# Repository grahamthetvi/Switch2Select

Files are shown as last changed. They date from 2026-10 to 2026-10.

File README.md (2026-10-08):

# Switch2Select

Switch2Select is a four-option switch device for students with cortical visual impairment. A student has four direct switches and one scan switch. A partner sees four toy outputs, volume buttons, a device button, and the power switch. One large target is on screen at a time. Choosing an option can light the ring behind that card, speak the port, show a picture, video, or simple game, and briefly close a contact for a battery toy.

An ESP32 DevKit runs an open Wi-Fi access point named Switch2Select and serves the page from a microSD card. A DFRobot Gravity Speech Synthesis Module V2.0 (DFR0760) speaks when no browser page is connected to the device. Two buttons change the volume. A third button, the same size, talks to the screen and repeats which port is in use. A DaierTek 20 mm round SPST rocker switches the USB +5 V lead from a power bank or a 5 V adapter. There is no custom circuit board. Connections are soldered or joined with WAGO 221 connectors.

A stand on the lid holds an iPad in landscape. The full stand leans 18 degrees back from vertical, and it can hold four 3 by 5 inch cards stood up in place of the iPad. The simple stand leans 8 degrees and holds the iPad. There is no lamp above the input jacks. Those lamps would point at the student. The active port is spoken, and the light sits behind the card.

Build in the order below. Flash the board before you close the box. Keep the power source unplugged until the wiring section is finished.

## Tools

- Soldering iron, or WAGO 221 lever connectors if you are not soldering
- Wire strippers
- Flush cutters
- Screwdriver for the lid screws and panel hardware
- 3D printer
- Computer with the Arduino IDE, a USB cable to the ESP32 for programming, and a way to copy files to a microSD card

## Parts

- ESP32 DevKit with USB, 30-pin style
- SPI microSD module
- microSD card you can format as FAT32
- Five panel-mount 3.5 mm mono jacks for the inputs. Each one pushes into a 9.1 mm hole
- Four panel-mount 3.5 mm mono jacks for the toy outputs, in the same 9.1 mm holes
- 4-channel 5 V relay module whose coils are off when the input pin is HIGH
- Four WS2812B rings, 7 LEDs each, 23 mm outside diameter, 5 V, with DIN and DOUT
- One 330 ohm resistor, in series with the ring data line
- One 1000 µF capacitor, 6.3 V or higher, across the ring 5 V and ground at the first ring
- Four 10k resistors for pull-ups
- Three momentary push buttons, 11.8 mm wide. The panel hole is 12.0 mm (11.8 mm plus 0.2 mm clearance) so the button can be pushed in
- DaierTek 20 mm 2-pin SPST round rocker
- DFR0760 speech module with the speaker it ships with
- USB cable for power
- USB power bank or 5 V USB adapter
- Insulated hookup wire
- Four small zip ties, or a dot of hot glue, to keep the rings in their pockets
- PLA or PETG
- Four M3 screws, about 8 mm to 12 mm long, for the lid
- For the full stand: four M3×20 mm screws and four M3 nuts, to bolt the cap and the plate through the lid; four M3×6 mm screws, for the two rail extensions; two M3×10 mm screws, for the sliding side rails; two M3×12 mm screws and two M3 nuts, to join the card halves; two M3×12 mm screws and two M3 nuts, for the rear feet
- For the simple stand: four M3×10 mm screws and four M3 nuts, to bolt the cradle through the lid; two M3×6 mm screws, for the side stops

The enclosure corners are drilled for the lid screws. The lid holes are 3.4 mm clearance. Each bottom boss has a 2.8 mm pilot, 10 mm deep. On the full stand, the extension screws and the rail screws form their own threads in 2.8 mm pilots. On the simple stand, each side-stop screw forms its own thread in the stop and presses on the lip. The screws that bolt a stand through the lid use nuts on the underside of the lid.

## Print the enclosure

The assembled box is 200 mm by 140 mm by 55 mm, with 2.4 mm walls. The outside vertical corners have a 6 mm radius. On the flat faces the wall is still 2.4 mm. Raised numerals and marks stand 0.8 mm off the walls. Braille dots stand 0.9 mm off the walls, so a finished bottom measures about 141.8 mm front to back. Print two parts:

- `enclosure/switch2select-bottom.stl`
- `enclosure/switch2select-lid.stl`

Those files were exported from `enclosure/switch2select.scad`. To export them yourself, open that file in OpenSCAD and set `part` to `"bottom"` or `"lid"`. The value `"both"` draws the bottom and the lid side by side. The customizer accepts `bottom`, `lid`, or `both`.

The two long walls are different. Look at the holes before you wire anything.

The student wall has four 9.1 mm jack holes in a row and one more 9.1 mm jack centered on the lower row. There is no lamp above those jacks. Input holes and output holes are the same size, so the female jack can be pushed in. On the inside of the wall, a cradle 27.3 mm deep holds the whole jack cylinder. A shoulder at the back of the cradle stops that cylinder, and a 7.0 mm hole through the shoulder (a 6.6 mm cord plus 0.4 mm clearance) lets the lead leave the back of the jack. A stem stands just past that hole, beside the cord path, so the lead can be wrapped after it leaves the cylinder and a pull does not yank the jack out. Raised numerals 1, 2, 3, and 4 sit beside the upper jacks. Grade 1 braille for 1, 2, 3, and 4 sits on the other side of those jacks. The center jack is the scan input. The braille word scan sits under it. Braille dots are 0.9 mm high and 1.6 mm across, with 2.5 mm between dot centers in a cell and 6.5 mm between cells. Facing this wall, the four option jacks run left to right as 1, 2, 3, 4. Their centers are 40 mm, 80 mm, 120 mm, and 160 mm from the left end. Input jacks are 28 mm up from the outside bottom. The scan jack is 16 mm up, at the middle of the wall (100 mm from either end).

The partner wall has four 9.1 mm toy-jack holes with the same 27.3 mm cradle, cord hole, and cord stem, and raised numerals 1, 2, 3, and 4. Grade 1 braille for 1, 2, 3, and 4 sits beside those jacks, on the side opposite the numeral. Numeral 1 is at the same end of the box as numeral 1 on the student wall. Toy jacks are 40 mm up from the outside bottom. The lower row, left to right when you face this wall, is:

- Volume down, a 12.0 mm hole (an 11.8 mm button plus 0.2 mm clearance) with a minus mark, 16 mm up. A 9 mm square backing sits 7.55 mm behind the inner face of the wall. Braille for the word minus is under the hole.
- Volume up, the same 12.0 mm hole, 9 mm square backing, and plus mark, 16 mm up. Braille for the word plus is under the hole.
- Device, the same 12.0 mm hole and 9 mm square backing, with a square mark, 16 mm up. Braille for the word use is under the hole. This button does not change the volume and it does not pulse a toy.
- Power rocker, a 20 mm hole, 16 mm up. The body behind the panel is about 25.4 mm deep, with snap wings and two terminals, and the inside stays clear so that body can sit in the box. Braille for the word power sits between this hole and the toy jacks.
- USB cable slot, 12 mm wide by 8 mm tall, centered 16 mm up
- microSD slot, 16 mm wide by 3 mm tall, centered 16 mm up

The lid has a speaker grill in the center. The grilled area is 42 mm by 32 mm, with seven slots, each 3 mm wide. Behind the grill, toward the partner edge, a 12 mm by 10 mm port lets the ring cable into the box. Four 3.4 mm holes in a row take the stand bolts. The lid lip is sized with a 0.4 mm gap inside the bottom rim. If a lid will not seat, sand the lip lightly until it drops in.

Inside, on the floor under that port, two posts and a bar are a tie point for the ring cable.

The enclosure, the stand, and the wiring are CERN-OHL-W v2. If you share a modified enclosure, stand, or wiring layout, release those hardware changes under the same license. The full terms are in the License section.

## Print the stand

The lid has four 3.4 mm holes in a row behind the speaker grill. The full stand and the simple stand both bolt through those holes. Print one stand. The student looks at the screen, or at the cards on the full stand. The partner wall stays open, so the toy plugs, the buttons, the rocker, the USB lead, and the microSD card are still reachable.

### Full stand

The full stand leans 18 degrees back from vertical. It holds an iPad or four cards. Two feet drop to the table at the rear corners, clear of the partner-wall plugs.

Print:

- `enclosure/stand-cap.stl`, one. The word FRONT is the student edge. The ring pockets are not on this part. Lay it flat, text up.
- `enclosure/stand-plate.stl`, one. Lay the flat foot on the bed. The back rises from it. The part is about 175 mm tall, so the printer needs that much vertical room. The ledge sticks out at about 18 degrees above the bed. Turn supports on under the ledge.
- `enclosure/stand-extension-left.stl` and `enclosure/stand-extension-right.stl`, one each. Same orientation as the plate, with supports under the ledge. Each is about 138 mm wide and 175 mm tall.
- `enclosure/stand-rail.stl`, two. Print one as exported and mirror the other in the slicer. The slot faces up. The small fin is the side that meets the iPad or the card panel. After mirroring, the two fins face each other.
- `enclosure/stand-cards-left.stl` and `enclosure/stand-cards-right.stl`, one each, only if you want the cards. Lay them with the round pockets up. Numerals 1 and 2 are on the left half. Numerals 3 and 4 are on the right half. Each half is about 183 mm by 151 mm.
- `enclosure/stand-foot.stl`, two. Lay it on the broad face. The screw hole is the short tunnel through the tab.

The cap, the rails, the card halves, and the feet print without supports.

Those files were exported from `enclosure/stand.scad`. Set `part` to `cap`, `plate`, `extension-left`, `extension-right`, `rail`, `cards-left`, `cards-right`, or `foot`. The value `assembly` draws the stand on the box, with a sample iPad and the card panel in the same ledge so you can see that both fit. You use one or the other, not both at once.

The ledge is 12 mm deep, so a bare iPad from 5.1 mm to 7.5 mm thick sits in it, and so does the card panel. A case has to be thinner than 11 mm. The iPad leans on the back. The shelf at the bottom of the slope keeps it from sliding toward the student. A low wall stands at the front of that 12 mm channel. The side rails set the width. Ticks on the ledge read `mini`, `10`, `13`, and `card`. Snug the rails to the real device. The `10` tick is the 10.2 inch iPad (7th, 8th, and 9th generation). The 10.9 inch and 11 inch Air and Pro models are within 3 mm of that tick.

Landscape widths, long edge on the ledge:

| Model | Width | Height | Thickness |
| --- | --- | --- | --- |
| iPad mini 6 and 7 | 195.4 mm | 134.8 mm | 6.3 mm |
| iPad 9.7 inch | 240 mm | 169.5 mm | 6.1 mm to 7.5 mm |
| iPad 7th, 8th, and 9th generation (10.2 inch) | 250.6 mm | 174.1 mm | 7.5 mm |
| iPad 10th generation and iPad A16 (10.9 inch) | 248.6 mm | 179.5 mm | 7.0 mm |
| iPad Air 11 inch and iPad Pro 11 inch (2018–2022) | 247.6 mm | 178.5 mm | 5.9 mm to 6.1 mm |
| iPad Pro 11 inch M4 | 249.7 mm | 177.5 mm | 5.3 mm |
| iPad Air 13 inch and iPad Pro 12.9 inch | 280.6 mm | 214.9 mm | 5.9 mm to 6.4 mm |
| iPad Pro 13 inch M4 | 281.6 mm | 215.5 mm | 5.1 mm |

Portrait works too. Slide the rails in until they touch the sides. The center plate alone is 200 mm wide, which covers an iPad mini in landscape. The side rails still need the two extensions under them, because the rail is wider than the spare ledge at the end of the center plate. Every larger iPad needs the extensions for the ledge as well. The card panel is 349 mm wide, so it needs the extensions too.

The cards are 3 inch by 5 inch (76.2 mm by 127 mm), stood up, four across. The slot is 1.6 mm wider and 1.8 mm deep, so a laminated card slides in from the top. To use a different card, change `card_w` and `card_h` at the top of `enclosure/stand.scad` and export the two card halves again.

Behind each card is a round seat 23.8 mm across and 2.4 mm deep, open on the back, with a 10 mm hole through to the card. That is the pocket for a 23 mm WS2812B ring. The 10 mm hole is smaller than the ring, so the ring cannot fall toward the student. Two 2.6 mm holes beside the seat take a zip tie across the back of the ring. A trench on the back carries the wires to the notch in the plate, then through the port in the cap and the lid.

Bolt the extensions to the plate with the four M3×6 screws. The thin lap on each extension sits in the recess at the end of the plate foot. The hole under the lap is about 7 mm deep and ends inside the foot, and an M3×6 screw draws the lap down. Bolt the cap and the plate foot to the lid with the four M3×20 screws and nuts. The nuts are on the underside of the lid, so do this before you screw the lid onto the box, or take the lid off to reach them. The four holes are in a row behind the speaker grill. The word FRONT on the cap points at the student. Bolt a foot to each rear tab of the cap. The leg reaches the table, 176 mm from the student edge. Fit both feet. The center of a 10.2 inch iPad sits about 5 mm behind the box, and the center of a 13 inch iPad sits about 13 mm behind the box. The feet carry that weight.

Slide a side rail onto each end of the ledge, with the extensions already bolted on, and tighten its screw until the rail stays put. For an iPad, set the rails to the width and sit the iPad on the ledge, long edge down, screen toward the student. For cards, screw the two halves together with the two M3×12 screws and nuts. The nuts sit in the hex pockets on the back of the half marked 1 and 2. Press each ring into a pocket from the back, LEDs toward the card, and tie or glue it. Seat the panel in the ledge and bring the rails in against its sides. The cable drops through the port. Tie it to the bar on the floor of the box.

### Simple stand

The simple stand is one cradle and two side stops. The back leans 8 degrees from vertical and is 6 mm thick. The cradle's outside corners have a 6 mm radius, and the edges of the back have a 2 mm radius. Each side stop's outside corners have a 1 mm radius. The lip the stops grip stays straight. Behind that plate, the cradle fills in to the rear edge of the shelf, so the back is solid where it joins the base. A bare iPad sits on the shelf and rests against that back. The lip on the student side of the shelf is 8 mm tall and 2.4 mm thick. The open gap from the lip to the back is 13.5 mm, so an iPad from 5.1 mm to 7.5 mm thick can lean fully back. The lip stops the bottom edge if the iPad slides toward the student. The lip starts about 1 mm behind the speaker grill, so the grill stays clear.

Eight degrees is a small lean, and it holds the iPad against the back. The center of a 13 inch iPad (215.5 mm tall and 5.1 mm thick) lands about 24 mm in front of the rear edge of the box. The cradle carries that iPad on the lid. The back is 160 mm along the slope, which covers an iPad mini. The top of a 10 inch or 13 inch iPad stands above the back and still leans on it.

Print:

- `enclosure/stand-simple.stl`, one. Lay the flat base on the bed. The lip and the back rise from it. The part is about 165 mm tall. It prints in PLA or PETG without supports.
- `enclosure/stand-simple-stop.stl`, two. Lay each one as exported. The slot faces up and the flat cap is on the bed. The fin is the short upright at one end. The part is about 74 mm long and 12 mm tall. Mirror the second stop left to right in the slicer, so the fins face each other and both screw bosses stay on the student side of the lip.

Those files were exported from `enclosure/stand-simple.scad`. Set `part` to `cradle` or `stop`. The value `assembly` draws the cradle and the stops on the box with a 13 inch iPad.

The cradle is 200 mm wide. An iPad mini in landscape (195.4 mm) sits on it with the stops near the ends. Each stop reaches about 45 mm past the box, which covers the wider models through a 13 inch iPad (281.6 mm). The widths are in the table above. Slide each stop on from the end of the lip until the fin meets the iPad.

Bolt the cradle to the lid with four M3×10 screws and nuts. Use a socket head or a pan head, about 5.5 mm to 5.6 mm across, so the head sits in the counterbore. Each counterbore is 6.2 mm across and 3.2 mm deep. The nuts are on the underside of the lid, so do this before you screw the lid onto the box, or take the lid off to reach them. The lip faces the student. The cable port stays open through the shelf.

Set the iPad on the shelf, long edge down, screen toward the student. It leans on the back. Bring each stop in until the fin touches the side. The M3×6 screw goes through the boss on the student side of the stop and presses the face of the lip. Tighten it until the stop stays put.

The card panel, the ring pockets, and the rear feet belong to the full stand.

## Flash the firmware

Flash the ESP32 before you mount it and before you depend on the relay pins. The sketch drives the relay outputs HIGH, which holds the coils off.

1. Install the Arduino IDE.
2. In Boards Manager, install the **esp32** package by Espressif Systems.
3. Under Tools, Board, choose **ESP32 Dev Module** (the `esp32dev` board). Leave the other board options at the package defaults unless your DevKit needs a different flash size.
4. In Library Manager, install these libraries:
   - **ArduinoJson** by Benoit Blanchon, version 6. This sketch uses `DynamicJsonDocument`. ArduinoJson 7 does not provide that type.
   - **WebSockets** by Markus Sattler (Links2004). The sketch includes `WebSocketsServer.h` from that library.
   - **DFRobot_SpeechSynthesis_V2**. This library is MIT, copyright DFRobot Co.Ltd. Keep their copyright notice with the library.
   - **Adafruit NeoPixel** by Adafruit. The sketch includes `Adafruit_NeoPixel.h`. On the ESP32 this library drives the rings with the RMT peripheral, so the Wi-Fi radio can stay up.
5. Open `firmware/Switch2Select/Switch2Select.ino`. Leave `pins.h`, `device.h`, `device.cpp`, `web.h`, and `web.cpp` in that same folder. The folder name stays `Switch2Select`.
6. Plug the DevKit into the computer with its own USB cable. The power-bank cable stays unplugged. Select the serial port that appears. If no port appears, install the USB serial driver for the chip on your board.
7. Upload the sketch.
8. Open the Serial Monitor at **115200** baud. After reset, the monitor prints the access-point address. With the ESP32 Arduino core defaults, that address is `192.168.4.1`.

The USB serial port and the speech module both use 115200. They are separate UARTs. Speech is on Serial2, pins 16 and 17, described below.

### Pins

GPIO 0, 2, and 12 are strapping pins. Leave them unconnected.

| Option | Numeral | Input GPIO | Input pull-up | Relay GPIO |
| --- | --- | --- | --- | --- |
| 0 | 1 | 34 | External 10k to 3.3 V | 4 |
| 1 | 2 | 35 | External 10k to 3.3 V | 15 |
| 2 | 3 | 36 | External 10k to 3.3 V | 21 |
| 3 | 4 | 39 | External 10k to 3.3 V | 22 |

Other connections:

- Scan jack: GPIO 32. Internal pull-up. The sketch enables it.
- Volume up (plus button): GPIO 27. Internal pull-up.
- Volume down (minus button): GPIO 33. Internal pull-up.
- Device button (square mark): GPIO 14. Internal pull-up.
- Card rings: GPIO 13 is the data pin. One chain of four 7-LED rings. GPIO 25 and GPIO 26 are unused.
- Speech, Serial2: GPIO 16 is the ESP32 receive pin and goes to the module D/T pin. GPIO 17 is the ESP32 transmit pin and goes to the module C/T pin. 115200 baud, 8 data bits, no parity, 1 stop bit.
- microSD SPI: CS GPIO 5, MOSI GPIO 23, MISO GPIO 19, SCK GPIO 18.

GPIO 34, 35, 36, and 39 are input-only. They have no internal pull-up. Each one needs the external 10k to 3.3 V. The scan, volume, and device pins use the ESP32 internal pull-ups, so they do not get a 10k resistor.

A press is active-low. The firmware accepts it after the pin has been low and stable for 40 ms. Holding a switch does not repeat the action.

## Prepare the microSD card

Format the card FAT32. Copy the files and folders that are inside `sd-card` so that `config.json` sits at the root of the card, next to `www`, `media`, and `games`.

These paths are part of the project:

- `/config.json`
- `/www/index.html`
- `/www/style.css`
- `/www/app.js`
- `/www/switch2select.js`
- `/www/edit.html`
- `/www/edit.css`
- `/www/edit.js`
- `/www/isolate.js`
- `/media/yes.svg`
- `/games/common.css`
- `/games/look/index.html`
- `/games/chase/index.html`
- `/games/pop/index.html`
- `/games/drum/index.html`

`yes.svg` is a yellow circle on a black square. The sample Play choice opens `/games/look/index.html`. Look keeps one yellow shape moving on black. Chase sends a ball between four places. Pop raises bubbles in four columns. Drum is four drums. In each game the four switches play the four places, left to right, and the scan switch plays too. A game keeps those switches while it is open. The choices return after the switches have been quiet for about a minute. The device button leaves sooner.

The sample `config.json` points the Look option at `/media/pulse.mp4`, which is included. The firmware serves `.html`, `.css`, `.js`, `.json`, `.svg`, `.mp4`, `.wav`, `.png`, `.jpg`, and `.jpeg`.

The device reads `/config.json` at startup. The setup page can write that file and apply it while the device stays on. After you edit the file on a computer, turn the rocker off and on. Use a plain text editor and keep the JSON valid, with exactly four objects in `options`. A file the firmware cannot parse is ignored in memory. The card copy is left as written. The in-memory fallback is auto scan, a 3 second step, a 1 second pulse length, volume 5, and the labels One, Two, Three, and Four, with toy pulses off.

Fields:

- `scanMode` is `"auto"` or `"step"`. Any value other than `"step"` is treated as auto. Auto is the sample and the fallback.
- `scanDelayMs` is how long, in milliseconds, the highlight stays on one option during auto scan. A missing or zero value becomes 3000.
- `outputPulseMs` is how long, in milliseconds, a toy contact stays closed. A missing value becomes 1000. The sample uses 1000, about one second.
- `volume` is an integer from 0 to 9. The sample uses 5. The volume buttons and the setup page update this field on the card when the card is mounted. Values below 0 or above 9 are clamped.
- `ringLevel` is an integer from 0 to 9. The sample uses 4. It sets how bright the card ring is. 0 leaves the rings off. The device button does not change it. The setup page changes it. A file edit is used after the rocker is turned off and on. A missing value becomes 4.
- `options` is four entries. Index 0 is numeral 1.

Each option:

- `label` is the short word shown while scanning, and the word spoken when the highlight moves. The firmware keeps 47 characters.
- `phrase` is spoken when that option is selected and the speech module is the one talking. If `phrase` is empty, the module speaks `label`. The firmware keeps 95 characters.
- `type` is `image`, `video`, `game`, or `tts`. An empty or unknown type is treated as `tts`.
- `src` is a path on the card, such as `/media/yes.svg`. Leave it empty for a `tts` option. The firmware keeps 63 characters.
- `background` is the screen color behind the target, as `#RRGGBB`. Empty becomes `#000000`.
- `color` is the word color, as `#RRGGBB`. Empty becomes `#ffff00`.
- `pulseOutput` is `true` or `false`. `true` closes that option's relay for `outputPulseMs` when the option is selected. `false` leaves the toy contact open. A missing flag is false.

The sample card is:

| Numeral | Label | Type | On select | Toy pulse |
| --- | --- | --- | --- | --- |
| 1 | Yes | image | Yellow circle, speaks "Yes" | Yes |
| 2 | Look | video | Plays `/media/pulse.mp4`, speaks "Look" | No |
| 3 | Play | game | Look game, speaks "Play" | No |
| 4 | Help | tts | Shows and speaks "I need help" | Yes |

Backgrounds in the sample are black. Word colors are yellow, except Look, which is red.

## Wiring

Unplug the power bank or adapter. Leave the rocker off. The DevKit may stay on the bench until the joints are done.

The DaierTek rocker switches the USB +5 V lead only. It must not be wired to household mains. Toy jacks are dry contacts on the relay normally-open pair, for a battery toy's own switch circuit. They are not a motor supply and they are not mains.

Use the tip and sleeve lugs on each mono jack. If a jack has an extra lug that switches when a plug is inserted, leave that lug unused.

### Power and ground

Cut the red conductor of the USB power cable and put the rocker in series with it. The rocker has two pins. One pin is the red wire from the power bank or 5 V adapter. The other pin is the switched +5 V that feeds the electronics. Black ground does not go through the rocker. Run ground straight through to:

- ESP32 GND
- Relay module GND
- DFR0760 GND
- SPI microSD module GND

Switched +5 V goes to:

- The ESP32 pin labeled 5V or VIN
- Relay module VCC
- DFR0760 5 V
- The card rings' 5 V pads, with the 1000 µF capacitor across that pair at the first ring

Program the board from the DevKit USB socket with this power cable unplugged, so the computer and the power bank are not both feeding 5 V. The enclosure slot is the exit for the power cable. It is 12 mm by 8 mm.

The 10k pull-ups use the ESP32 pin labeled 3.3V. They do not use 5 V.

### Relays and toy jacks

HIGH on a relay GPIO means the coil is off. The firmware writes HIGH on GPIO 4, 15, 21, and 22 before it sets those pins as outputs, so a reset does not pulse a toy. Use a 4-channel 5 V module that works this way: a HIGH input leaves the coil off, and a LOW input turns that coil on.

If the board has a jumper between JD-VCC and VCC, leave the jumper fitted. The coils then use the same switched 5 V as the rest of the module. This build has no separate coil supply.

One relay channel serves one option:

- Numeral 1, relay input GPIO 4
- Numeral 2, relay input GPIO 15
- Numeral 3, relay input GPIO 21
- Numeral 4, relay input GPIO 22

For each channel, connect the normally-open terminal (NO) and the common terminal (COM) to the tip and sleeve of that option's toy jack. Either lug may take either relay terminal. A dry contact has no polarity from this device. Leave the normally-closed terminal (NC) unconnected. No ESP32 pin connects to a toy jack. The toy plug replaces the toy's own switch: the two conductors that the toy's button used to join. When the firmware selects an option with `pulseOutput` true, it drives that GPIO LOW for `outputPulseMs`, then returns it HIGH.

### Input jacks and volume buttons

Each input jack: sleeve to GND, tip to its GPIO.

- Numeral 1 tip: GPIO 34, and a 10k resistor from that GPIO to 3.3 V
- Numeral 2 tip: GPIO 35, and a 10k resistor from that GPIO to 3.3 V
- Numeral 3 tip: GPIO 36, and a 10k resistor from that GPIO to 3.3 V
- Numeral 4 tip: GPIO 39, and a 10k resistor from that GPIO to 3.3 V
- Scan tip: GPIO 32. Sleeve to GND. No external resistor.

Volume buttons and the device button are momentary switches, not jacks. One side of each button goes to GND.

- Plus button, the volume-up mark: GPIO 27
- Minus button, the volume-down mark: GPIO 33
- Device button, the square mark: GPIO 14

Match numeral 1 on the student wall to numeral 1 on the partner wall. The walls face opposite directions, so the left-hand jack on one wall is not numeral 1 on the other wall.

### Card rings

The rings replace lamps on the student wall. Only the ring behind the highlighted card is on. Its color is that option's `color`. `ringLevel` in `config.json` is 0 through 9. The sample uses 4. Level 0 leaves every ring dark. The firmware never turns all four rings on at once.

Power the rings from the switched 5 V rail, the same rail as the ESP32 VIN pin. Do not power them from the 3.3 V pin. Ground is the common ground. Put the 1000 µF capacitor across 5 V and ground at the first ring.

GPIO 13 goes to the 330 ohm resistor. The other side of the resistor goes to DIN on the port 1 ring. Port 1 is the student's left, the same end as numeral 1. Chain DOUT of each ring to DIN of the next, left to right, port 1 then 2 then 3 then 4. Share 5 V and ground with every ring. Keep the data lead short. These rings usually take the ESP32's 3.3 V data over that short lead. If the first ring never lights, the speech and the page still work.

At startup the firmware lights the port 1 ring and leaves the other three off. That ring follows the highlighted port afterward. The pocket is 23.8 mm across. Seat the ring from the back of the card panel, LEDs toward the card, and hold it with a zip tie through the two holes beside the pocket or with a dot of hot glue. The 10 mm hole in front of the ring lets the light reach the back of the card.

### Speech module

Set the switch on the DFR0760 to UART before you apply power. Connect module 5 V and GND as in the power step. The speaker stays on the module's speaker terminals.

- Module D/T to ESP32 GPIO 16
- Module C/T to ESP32 GPIO 17

D/T is the module's transmit pin. C/T is the module's receive pin. The firmware talks to it at 115200 baud and sends the stored volume after the module answers.

### microSD module

- CS to GPIO 5
- MOSI to GPIO 23
- MISO to GPIO 19
- SCK to GPIO 18
- GND to the common ground

Power the SPI module from the supply printed on that board. A module marked for 5 V, with its own regulator, uses the switched 5 V rail. A 3.3 V module uses the ESP32 3.3 V pin. Seat the module so a card pushed through the 16 mm by 3 mm slot enters the socket.

### Pins to leave alone

Do not use GPIO 0, 2, 12, 25, or 26. Do not land a toy jack, a relay contact, or the rocker on an ESP32 pin. Before you apply power, check that each toy jack's two lugs go only to one relay's NO and COM.

## Assembly

1. Confirm the student wall by the single lower jack with the braille word scan under it. There are no lamp holes on that wall. Confirm the partner wall by the 20 mm rocker hole, the three button holes (minus, plus, and the square mark), and the two slots.
2. Push the four input jacks and the scan jack into the 9.1 mm holes until each 27.3 mm cylinder sits in its cradle against the back shoulder. Feed each lead out through the cord hole and wrap it around the stem just beyond that hole.
3. Push the four toy jacks into the partner-wall holes the same way, each beside its matching numeral, and wrap those leads on the stems beyond the cord holes. Seat each of the three buttons in its hole so it meets the 9 mm square backing. Mount the 20 mm rocker in the lower row. Leave the space behind the rocker clear for the switch body and its two terminals.
4. Route the USB power cable out through the 12 mm by 8 mm slot.
5. Place the microSD socket behind the 16 mm by 3 mm slot.
6. Place the DFR0760 speaker on the inside of the lid, facing the grill. Bolt the stand to the lid before this lid goes back on the box, so you can reach the nuts. On the full stand, that is the cap and the plate with the four M3×20 screws. On the simple stand, that is the cradle with the four M3×10 screws, heads in the counterbores. The ring cable comes through the 12 mm by 10 mm port and ties to the bar on the floor. The simple cradle leaves that port open.
7. Label the outside of the student wall **Inputs** and the outside of the partner wall **Toys**. The raised numerals show which channel is which. The written labels are there so the two jack types are not swapped later.
8. Insert the FAT32 card.
9. Set the lid on the rim and fasten the four M3 screws through the lid into the corner bosses. The stand, if you bolted it to the lid, comes with the lid.

## Power-on test

This is the behavior the firmware and the sample card are written to produce. Work through it in order. Use the sample `config.json`, which is auto mode.

1. Toys unplugged or plugged into the partner-wall jacks only. Turn the rocker on. The relays stay silent and the toy contacts stay open. If the speech module is connected and no browser is open, it says "Port one, Yes". If the card rings are wired, the port 1 ring lights in that option's color and the other three stay off. Nothing on the student wall lights.
2. On a phone, iPad, or computer, join the Wi-Fi network **Switch2Select**. The sketch sets no password.
3. Open `http://192.168.4.1`. The device redirects to the page on the card. You should see a single target, the Yes image (a yellow circle) for the sample's first option. The page says "Port one, Yes".
4. Press the switch plugged into input 1. The page selects Yes. The picture pops and stays while the word is spoken. Auto scan waits during that. Press input 4. The page selects Help and shows the words for that option. The matching ring is the one that lights.
5. Wait until the words have finished. In the default auto mode the highlight then moves about every 3 seconds, the page follows it, and the spoken port changes with it. The ring follows the same port.
6. Press the scan jack while an option is highlighted. In auto mode that press selects the highlighted option. It does the same work as pressing that option's direct jack, including the toy pulse when `pulseOutput` is true.
7. Press the plus and minus buttons. Volume moves in steps from 0 through 9 and is written back to `config.json` on the card. With the page open, that level is the browser speech level. With the page closed, it is the DFR0760 level. Press the device button (the square mark). It does not move the highlight and it does not pulse a toy. It says the port that is in use, for example "Port one, Yes". With the page open, a video starts again from the beginning. While a game is open, this button leaves the game and says the port. The four switches and the scan switch play the game.
8. Plug a battery toy's switch lead into toy jack 1 or toy jack 4. Select Yes or Help. The contact closes for about one second (`outputPulseMs` is 1000) and then opens. Select Look or Play. Those sample options have `pulseOutput` false, so their toy jacks stay open.
9. Close the browser page so nothing is connected to the device. Select Help again. The DFR0760 speaks "Port four, I need help". The toy contact still opens when the one-second pulse ends, including while the module is still speaking.

If the page is open and the module still speaks, reload the page. Speech belongs to the browser while a page is connected, and to the DFR0760 when it is not. Joining the Wi-Fi network without opening the page leaves speech on the module.

If the module never speaks with the page closed, check that its switch is on UART, that D/T goes to GPIO 16, and that C/T goes to GPIO 17.

### If a check fails

**Input and toy jacks swapped.** A press on the student wall does nothing to the highlight, because that jack is only a relay contact. A toy plugged into an input jack is on a GPIO and ground, which does not give it a timed relay closure. Turn the rocker off, unplug every toy, and move the jacks: inputs on the wall with the scan jack, toy outputs on the wall with the rocker.

**A relay clicks at boot.** A coil turned on. This firmware holds GPIO 4, 15, 21, and 22 HIGH, and HIGH means the coil is off on the module this guide uses. A click means an IN wire is on the wrong pin, that pin is being held low, or the module turns its coil on when the input is HIGH. Recheck the four relay GPIOs. Leave GPIO 0, 2, and 12 unused.

**No microSD card, or a card the board cannot mount.** Switch2Select still appears, and the relay pins still idle HIGH. The browser reports that the page was not found, because the page files are on the card. Speech uses the fallback words One, Two, Three, and Four. Toy contacts stay open, because that fallback sets every `pulseOutput` flag false. Volume changes last only until power is removed.

## Using the device

A partner prepares the card and the toy leads. A student uses the five switches on the input wall.

The partner changes the four choices on the setup page. On the student screen, tap Setup in the top corner, or open `http://192.168.4.1/www/edit.html`. A phone that has joined Switch2Select can open that address and leave the student screen in place. Save writes the card, and the device uses the new settings while it stays on. The sketch has to be the one that accepts that save. Flash it, and copy the `www` files onto the card, before you rely on the page.

The page edits scan mode, the time on each choice, how long a toy stays on, volume, card-light brightness, and each choice. A picture can be taken or chosen on the iPad. Remove background lifts the subject off a plain background, such as paper or a table, and can draw an outline in a chosen color. That work runs in the browser. The device Wi-Fi does not reach the internet, so bring a photo with a plain background when you can. Videos need to be short MP4 files. Photos and videos from the page are stored as `/media/1.png` and `/media/1.mp4`, and the same pattern for choices 2, 3, and 4. A game stays a page already on the card. Look, Chase, Pop, and Drum are the ones on the card. The setup page has a button for each.

Editing `config.json` on a computer still works. Copy the card back, then turn the rocker off and on. Volume buttons still write the volume into the file while the device is on.

There are four options, numbered 1 to 4. Speech names the port that is highlighted, and the ring behind that card is the only one lit. One target fills the screen. Nothing on the input wall points a lamp at the student.

**Auto** is the default (`scanMode` set to `"auto"`). The highlight moves on its own every `scanDelayMs` (3 seconds on the sample card). The scan switch selects the option that is in use. A direct switch selects that option immediately, in auto mode and in step mode.

**Step** (`scanMode` set to `"step"`) does not move the highlight by itself. The scan switch only moves the highlight to the next option. It does not select and it does not pulse a toy. The four direct switches still select.

A selection always updates the ring and the page. It closes that option's toy contact only when `pulseOutput` is true, and only for `outputPulseMs`.

Choosing a picture, words, or a video pauses auto scan so the student can look. A picture or the words stay up long enough to be spoken, then the scan continues from that choice. A video stays until it ends, or for about a minute and a half if it does not end. Choosing the same picture, words, or video again plays it again.

Choosing a game pauses auto scan and lends the five student switches to that game. Later presses stay in the game: they do not move the four choices and they do not pulse a toy. The opening press still can. The four direct switches play four places, left to right, matching jacks 1 to 4. The scan switch plays the moving bright place, or the next place in Look and Chase. The game keeps moving while it waits, so there is something to look at between presses. Presses keep the game open. After the switches have been quiet for about a minute, the choices return and auto scan continues from that game. The device button leaves at once and says the port. It does not play the game.

Speech depends on the page:

- While a browser has the page open, the browser speaks and the DFR0760 stays quiet.
- While no page is connected, the DFR0760 speaks the same moments. Moving the highlight speaks "Port one, Yes" and so on: the port, then the option `label`. Selecting an option speaks the port and then `phrase`, or `label` when `phrase` is empty.
- While a browser has the page open, moving the highlight speaks that same port cue. Selecting speaks the phrase, or the label, without the port in front of it, so the screen says the message.

The device button is the square mark on the partner wall. It does not select an option, move the scan, or close a toy contact. It repeats the port that is in use. On the page it also acts on what is already showing. A video plays again from the start. A picture or words are spoken again. While a game is open, the button leaves the game instead. With the page closed, the speech module only repeats the port cue.

On the page, scanning an `image` option shows the picture. Scanning any other type shows the label as a word. The word or picture eases larger and smaller so the screen is not still. Selecting an `image` pops the picture, a `video` plays `src`, a `game` loads `src` and then stays there while the switches play it, and a `tts` option shows the phrase (or the label if the phrase is empty). For `tts`, the browser speaks that phrase. For the other types, the browser speaks the label. A game is not loaded again on every switch. Each later switch is sent into the game.

Words drawn by `style.css` are bold uppercase Arial, with Helvetica Neue and then a generic sans-serif as the font fallbacks. The page uppercases the letters on screen. Speech still says the phrase as it is written in `config.json`. The letter fill is the option `color`. A red outline surrounds each letter. The area behind the target is the option `background`. In the sample, that is yellow letters with a red outline on black, except Look, whose letters are red with the same red outline.

Volume is 0 through 9 on the two partner-wall buttons. The card stores the level.

## Attribution

The interaction pattern is inspired by Chatterbox, designed by Stephan Dobri for Neil Squire / Makers Making Change.

Copyright (c) 2025, Neil Squire. Chatterbox source: https://github.com/makersmakingchange/Chatterbox

Switch2Select firmware, enclosure, and this guide are original.

Copyright (C) 2026 Switch2Select contributors.

Chatterbox firmware and CAD were not copied into this project.

## License

- Firmware is GPL-3.0-or-later. The license text is in [LICENSES/gpl-3.0.txt](LICENSES/gpl-3.0.txt). Copyright (C) 2026 Switch2Select contributors.
- Enclosure and wiring (hardware) are CERN-OHL-W v2. The license text is in [LICENSES/cern_ohl_w_v2.txt](LICENSES/cern_ohl_w_v2.txt). If you share a modified enclosure or wiring, release those hardware changes under the same license.
- This guide is CC BY-SA 4.0. Credit Neil Squire / Makers Making Change for the Chatterbox interaction model this started from, and Switch2Select contributors for this device. The license text is in [LICENSES/cc-by-sa_4.0.txt](LICENSES/cc-by-sa_4.0.txt).
- The DFRobot_SpeechSynthesis_V2 library is MIT, copyright DFRobot Co.Ltd. Keep their notice with the library when you install it.

There is no warranty. Safety and quality of built units are on the maker. The power rocker switches 5 V USB only. It must not be wired to household mains. Toy jacks are dry contacts on the relay normally-open pair, for a battery toy's own switch circuit, not a motor supply or mains.

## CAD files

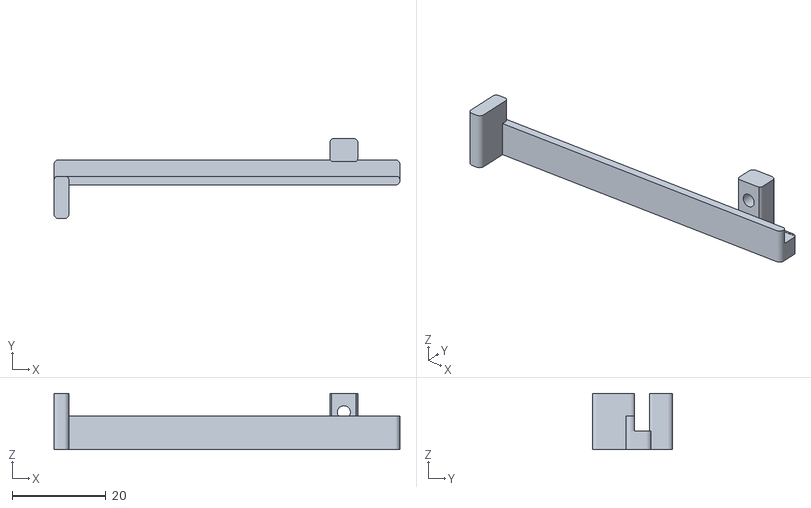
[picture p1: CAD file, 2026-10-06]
enclosure/stand-simple-stop.stl
74.0 x 17.2 x 12.1

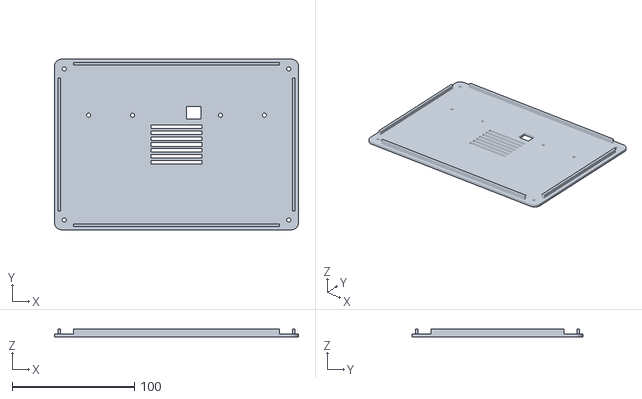
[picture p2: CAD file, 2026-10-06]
enclosure/switch2select-lid.stl
200.0 x 140.0 x 6.40

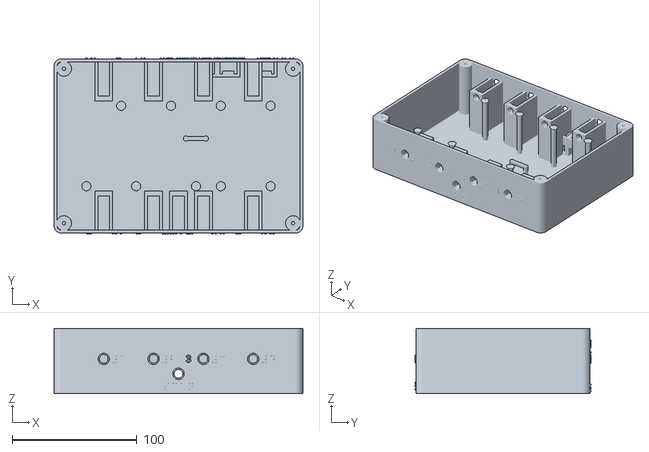
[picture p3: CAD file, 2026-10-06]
enclosure/switch2select-bottom.stl
200.0 x 141.8 x 52.6

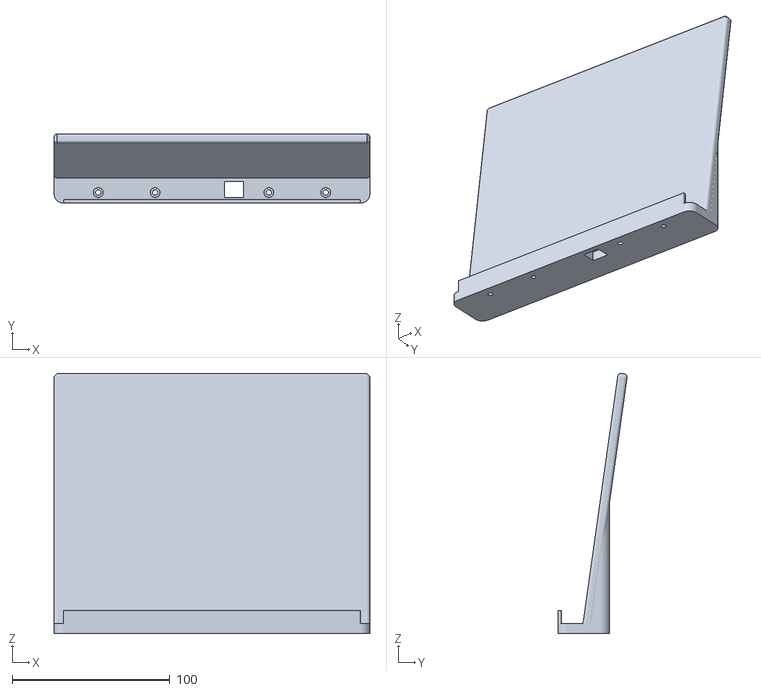
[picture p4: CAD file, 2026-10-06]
enclosure/stand-simple.stl
200.0 x 43.8 x 164.7

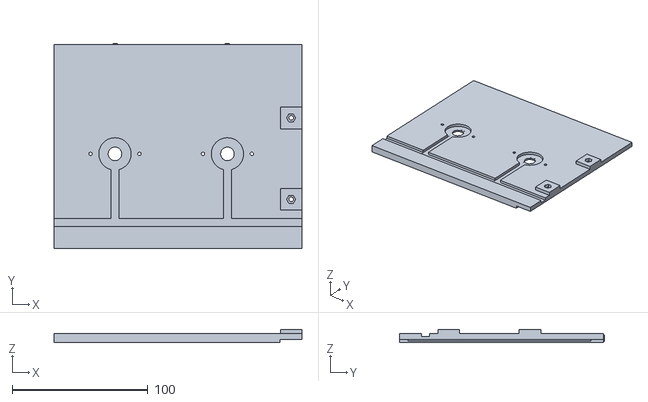
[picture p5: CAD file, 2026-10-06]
enclosure/stand-cards-left.stl
182.6 x 150.6 x 9.60

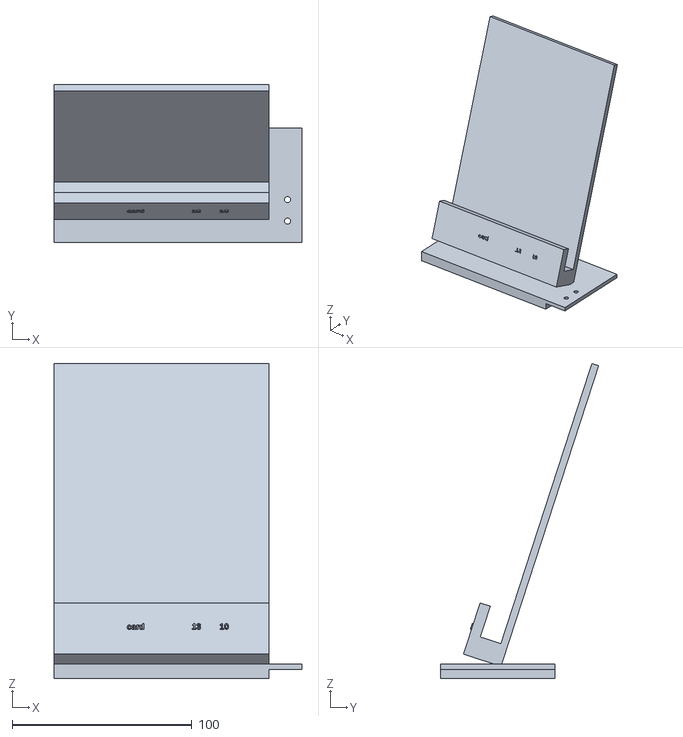
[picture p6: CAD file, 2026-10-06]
enclosure/stand-extension-left.stl
138.0 x 88.2 x 175.4

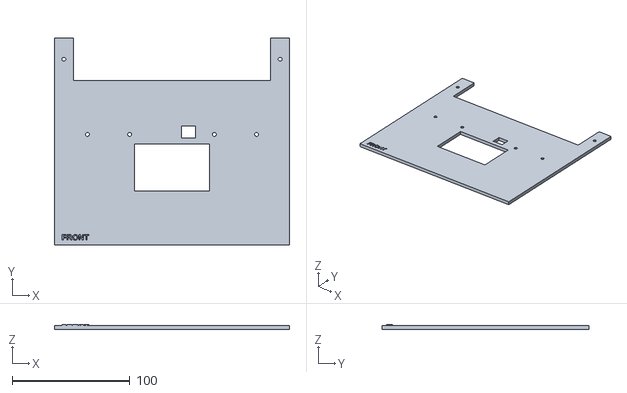
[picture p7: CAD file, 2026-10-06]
enclosure/stand-cap.stl
200.0 x 176.0 x 4.30

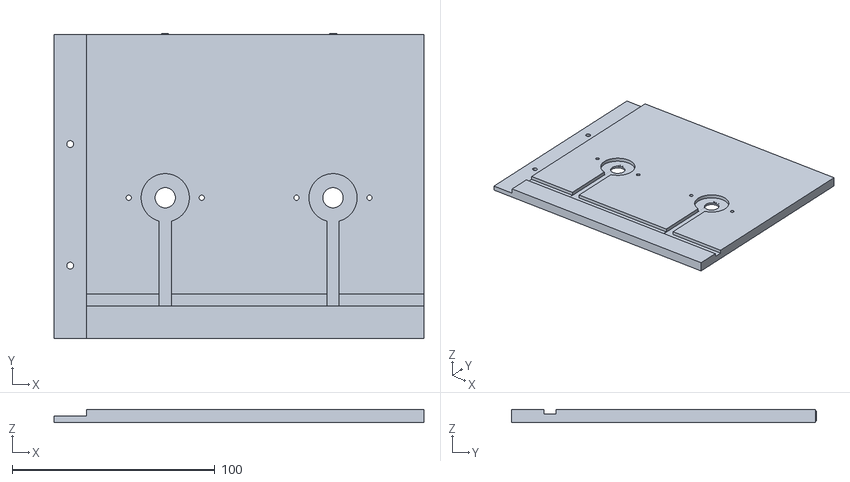
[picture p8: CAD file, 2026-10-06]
enclosure/stand-cards-right.stl
182.6 x 150.6 x 6.60

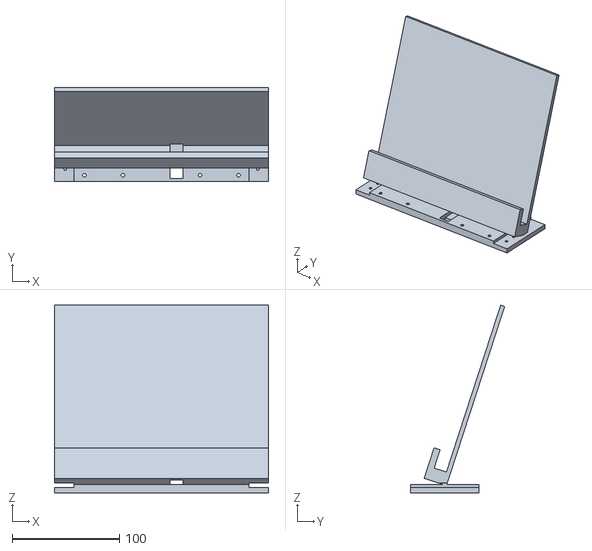
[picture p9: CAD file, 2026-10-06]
enclosure/stand-plate.stl
200.0 x 88.2 x 175.4

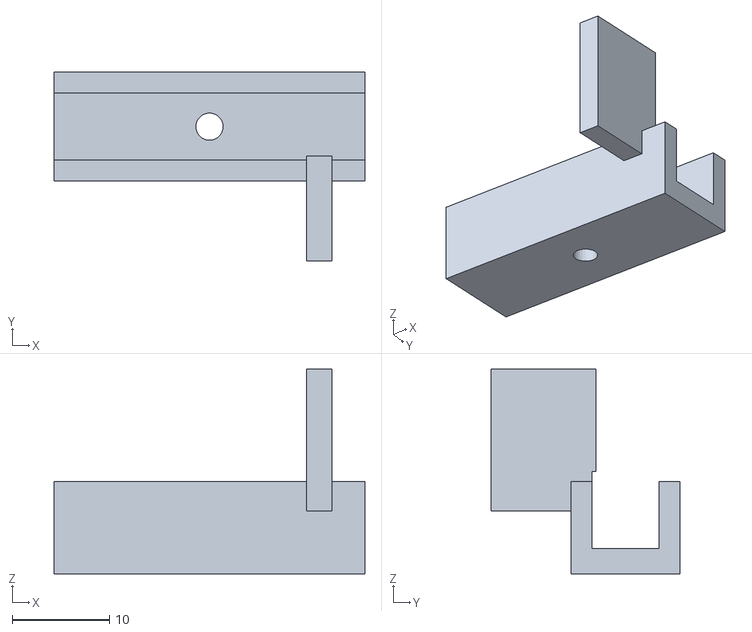
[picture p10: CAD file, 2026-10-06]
enclosure/stand-rail.stl
32.0 x 19.4 x 21.0

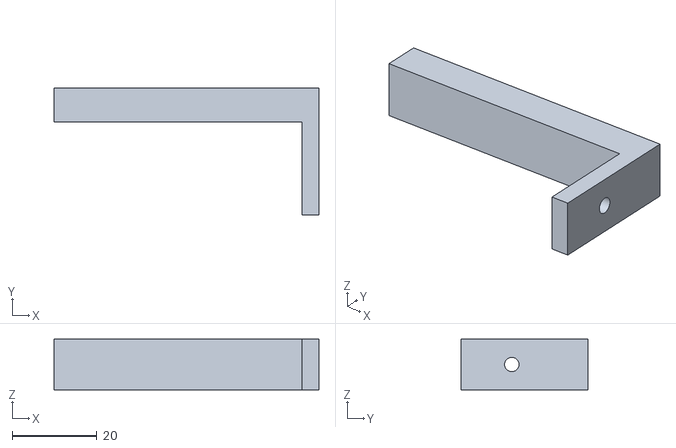
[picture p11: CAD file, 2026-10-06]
enclosure/stand-foot.stl
62.6 x 30.0 x 12.0

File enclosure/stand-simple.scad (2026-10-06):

// Switch2Select simple iPad stand
// Copyright (C) 2026 Switch2Select contributors
// SPDX-License-Identifier: CERN-OHL-W-2.0
//
// A second stand for the iPad. The full rail, card panel, and rear feet stay
// in enclosure/stand.scad. This one is a cradle and two side stops.
//
// The back leans 8 degrees from vertical. That is enough for a bare iPad to
// rest against the back. The center of a 13 inch iPad (215.5 mm tall,
// 5.1 mm thick) stays about 24 mm in front of the rear edge of the 140 mm
// box, so the cradle alone carries it.
//
// The lip is the low wall on the student side of the shelf. The clear gap
// from that wall back to the sloping back is `channel` (13.5 mm). A bare iPad
// from 5.1 mm to 7.5 mm thick sits on the shelf and leans on the back. The
// lip stops the bottom edge if it slides toward the student. About 2 mm of
// shelf remains behind the lid's cable port, under that bottom edge.
//
// Four M3 holes already in the lid (switch2select.scad) bolt the cradle down.
// Heads sit in counterbores so they stay below the shelf. The ring-cable port
// stays open through the shelf.
//
// Each side stop slides onto the lip from the end. The fin is the outer end
// and faces the iPad. The long body reaches past the box so a 13 inch iPad
// (281.6 mm wide) can be snugged up. An M3×6 screw through the boss presses
// the student face of the lip and keeps the stop from sliding.
//
// The back plate is 6 mm thick. A brace fills in behind it, out to the rear
// edge of the shelf, so the back is solid where it joins the base.
// Outside vertical corners of the cradle are 6 mm. The back's long edges
// and top are 2 mm. The lip the stops grip stays a straight rectangle.
//
// Print the cradle with the base on the bed. The back rises about 8 degrees
// off vertical, and the lip is a vertical wall, so it does not need supports.
// Print each stop as exported: the flat cap is on the bed and the slot faces up.

part = "cradle"; // [cradle, stop, assembly]

tilt = 8;
box_x = 200;
box_y = 140;
box_z = 55;
// Lid skin thickness in switch2select.scad. The cradle screws pass through it.
lid_t = 2.4;

base_t = 6.5;
back_t = 6;
back_len = 160;
base_y1 = 120;
// Outside vertical corners. The shelf top and the bolt face stay flat.
corner_r = 6;
// Long edges and the top of the back. The face the iPad leans on stays flat.
edge_r = 2;
// Outside corners of a side stop. The slot that grips the lip stays square.
stop_r = 1;

// Speaker grill is centered at y = 70 and is 32 mm front to back, so the
// partner edge of the grill is y = 86. The lip stays behind that edge.
grill_y1 = 86;
grill_x0 = 79;
grill_x1 = 121;
lip_y0 = 87.3;
lip_t = 2.4;
lip_h = 8;
channel = 13.5;

// Same centers as switch2select.scad and stand.scad.
stand_bolt_y = 94;
stand_bolt_xs = [28, 64, 136, 172];
m3_clear = 3.4;
m3_pilot = 2.8;
// Socket-head and pan-head M3 screws are about 5.5 mm to 5.6 mm across.
cbore_d = 6.2;
cbore_h = 3.2;
cradle_screw = 10;

ring_port_x = 114;
ring_port_y = 96;
ring_port_w = 12;
ring_port_h = 10;

// Side stop. The fin is the outboard end. The screw boss is near the inboard end.
stop_len = 74;
fin_t = 3.2;
fin_depth = 9;
top_t = 4;
bead = 1.8;
bead_h = 3.2;
clear_y = 0.4;
clear_z = 0.35;
boss_t = 5;
boss_extra = 6;
stop_screw = 6;
screw_x = 62;
gap = 0.8;

lip_y1 = lip_y0 + lip_t;
y_back = lip_y1 + channel;
lip_top = base_t + lip_h;
y_lip_partner = 12;
y_lip_student = y_lip_partner + lip_t;

function com_y(h, t) = y_back + (h / 2) * sin(tilt) - (t / 2) * cos(tilt);
function top_y(h) = y_back + h * sin(tilt);
function back_print_z() = base_t + back_len * cos(tilt);
// Where the partner face of the back meets the top of the shelf.
function back_root_y() = y_back + back_t * cos(tilt);
// How far up the slope that face stays over the shelf.
function brace_s() = (base_y1 - back_root_y()) / sin(tilt);
function back_partner_top_y() = y_back + back_len * sin(tilt) + back_t * cos(tilt);
function fin_x_for(w) = (box_x - w) / 2 - gap;
function screw_world(w) = fin_x_for(w) - fin_t + screw_x;

module m3_hole(h, d) {
  cylinder(h = h, d = d, $fn = 32);
}

// Vertical corners only, so the top and bottom faces stay flat.
module rounded_prism(size, r) {
  hull() {
    for (x = [r, size[0] - r])
      for (y = [r, size[1] - r])
        translate([x, y, 0])
          cylinder(h = size[2], r = r, $fn = 48);
  }
}

module shelf_round(h) {
  translate([0, lip_y0, 0])
    rounded_prism([box_x, base_y1 - lip_y0, h], corner_r);
}

// Solid fill behind the back, from the partner face out to the rear edge
// of the shelf, up to where that face reaches the rear edge.
module back_brace() {
  intersection() {
    hull() {
      translate([0, y_back, base_t])
        rotate([90 - tilt, 0, 0])
          translate([0, -1, -back_t])
            cube([box_x, brace_s() + 1, 1.2]);
      translate([0, back_root_y() - 0.4, base_t])
        cube([box_x, base_y1 - (back_root_y() - 0.4), 2]);
    }
    shelf_round(200);
  }
}

// Ends and the top are rounded. The bottom face stays square so it still
// bites into the shelf, and the student face stays flat for the iPad.
module back_plate() {
  len = back_len + 2;
  thick = back_t;
  r = edge_r;
  translate([0, -2, -thick])
    hull() {
      for (x = [r, box_x - r])
        for (z = [r, thick - r])
          translate([x, 0, z])
            rotate([-90, 0, 0])
              cylinder(h = len - r, r = r, $fn = 32);
      for (z = [r, thick - r])
        translate([r, len - r, z])
          rotate([0, 90, 0])
            cylinder(h = box_x - 2 * r, r = r, $fn = 32);
    }
}

// Straight front, round ends, same thickness the stop slot is cut for.
module lip_wall() {
  span = box_x - 2 * corner_r;
  r = lip_t / 2;
  translate([corner_r, lip_y0, base_t])
    hull() {
      translate([r, r, 0])
        cylinder(h = lip_h, r = r, $fn = 32);
      translate([span - r, r, 0])
        cylinder(h = lip_h, r = r, $fn = 32);
    }
}

module cradle() {
  difference() {
    union() {
      shelf_round(base_t);
      lip_wall();
      translate([0, y_back, base_t])
        rotate([90 - tilt, 0, 0])
          back_plate();
      back_brace();
    }
    translate([
      ring_port_x - ring_port_w / 2,
      ring_port_y - ring_port_h / 2,
      -1
    ])
      cube([ring_port_w, ring_port_h, base_t + 2]);
    for (x = stand_bolt_xs) {
      translate([x, stand_bolt_y, -1])
        m3_hole(base_t + 2, m3_clear);
      translate([x, stand_bolt_y, base_t - cbore_h])
        m3_hole(cbore_h + 1, cbore_d);
    }
  }
}

// Slot faces up. The flat cap is z = 0. The fin is the low-x end.
// The slot runs the whole length, so the lip can slide through. The fin
// stands only on the partner side of the lip.
module stop_solid() {
  y_bead0 = y_lip_partner - clear_y - bead;
  y_fin0 = y_lip_partner - clear_y - fin_depth;
  y_boss0 = y_lip_student + clear_y;
  y_boss1 = y_boss0 + boss_t;
  z_hole = top_t + lip_h / 2;
  fin_z = top_t + lip_h + clear_z - 0.3;
  bead_w = bead + 0.2;

  difference() {
    union() {
      translate([0, y_bead0, 0])
        rounded_prism([stop_len, y_boss0 + 0.4 - y_bead0, top_t], stop_r);
      translate([0, y_bead0, 0])
        rounded_prism([stop_len, bead_w, top_t + bead_h], bead_w / 2);
      translate([0, y_fin0, 0])
        rounded_prism([
          fin_t,
          y_bead0 + bead + 0.2 - y_fin0,
          fin_z
        ], stop_r);
      translate([screw_x - boss_extra / 2, y_boss0 - 0.2, 0])
        rounded_prism([boss_extra, boss_t + 0.2, top_t + lip_h], stop_r);
    }
    translate([-0.2, y_lip_partner - clear_y, top_t - 0.05])
      cube([
        stop_len + 1,
        lip_t + 2 * clear_y,
        lip_h + 2
      ]);
    translate([screw_x, y_boss1 + 1, z_hole])
      rotate([90, 0, 0])
        m3_hole(boss_t + clear_y + 2, m3_pilot);
  }
}

// fin_face is the X of the face that meets the iPad.
module stop_at(fin_face) {
  translate([
    fin_face - fin_t,
    lip_y1 + y_lip_partner,
    lip_top + clear_z + top_t
  ])
    rotate([180, 0, 0])
      stop_solid();
}

module mirror_center() {
  translate([box_x / 2, 0, 0])
    mirror([1, 0, 0])
      translate([-box_x / 2, 0, 0])
        children();
}

module stops_for(w) {
  stop_at(fin_x_for(w));
  mirror_center()
    stop_at(fin_x_for(w));
}

module ipad_ghost(w, h, t) {
  translate([0, y_back, base_t])
    rotate([90 - tilt, 0, 0])
      translate([(box_x - w) / 2, 0.45, 0.35])
        cube([w, h, t]);
}

module assembly() {
  color("ivory")
    cradle();
  color("tan")
    stops_for(281.6);
  color([0.2, 0.45, 0.75, 0.35])
    ipad_ghost(281.6, 215.5, 5.1);
  color([0.15, 0.15, 0.15, 0.25])
    translate([0, 0, -box_z])
      cube([box_x, box_y, box_z]);
}
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

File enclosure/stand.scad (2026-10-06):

// Switch2Select tablet and card stand
// Copyright (C) 2026 Switch2Select contributors
// SPDX-License-Identifier: CERN-OHL-W-2.0
//
// The stand sits on the lid. A rail at 18 degrees from vertical holds either
// an iPad or a four-card panel. Side pieces extend the rail past the box.
// Card rings sit in a pocket behind each card; the harness drops through the
// lid port cut by switch2select.scad.
//
// Landscape widths (long edge on the ledge), thickness last:
//   iPad mini 6/7                  195.4 x 134.8 x 6.3
//   iPad 9.7 (5th/6th, Pro 9.7)    240.0 x 169.5 x 6.1 to 7.5
//   iPad 7th/8th/9th (10.2)        250.6 x 174.1 x 7.5
//   iPad 10th / A16 (10.9)         248.6 x 179.5 x 7.0
//   iPad Air 11, Pro 11 (2018-22)  247.6 x 178.5 x 5.9 to 6.1
//   iPad Pro 11 M4                 249.7 x 177.5 x 5.3
//   iPad Air 13, Pro 12.9          280.6 x 214.9 x 5.9 to 6.4
//   iPad Pro 13 M4                 281.6 x 215.5 x 5.1
// Portrait works too: the rails slide. Ticks mark landscape widths.
// The channel is deeper than the thickest bare iPad (7.5 mm). A case has to
// stay under 11 mm thick.

part = "assembly"; // [assembly, cap, plate, extension-left, extension-right, rail, cards-left, cards-right, foot]

// Lid top is z = 0 for every part. The box is below that.
box_x = 200;
box_y = 140;
box_z = 55;
cap_t = 3.6;

tilt = 18;
plate_rot = 90 - tilt;
plate_t = 4;
plate_w = 200;
plate_h = 176;
foot_t = 8;
foot_y0 = 88;
foot_y1 = 152;
hinge_y = 118;
ext_w = 120;
lap_x = 18;
lap_t = 3;
part_gap = 0.35;

// Same centers as switch2select.scad.
stand_bolt_y = 94;
stand_bolt_xs = [28, 64, 136, 172];
m3_clear = 3.4;
m3_pilot = 2.8;
ring_port_x = 114;
ring_port_y = 96;
ring_port_w = 12;
ring_port_h = 10;

channel_d = 12;
floor_y = 12;
stop_rise = 12;
stop_z0 = channel_d;
stop_z1 = channel_d + 6;
rib_h = 6;
rib_y0 = floor_y + stop_rise;
rib_y1 = rib_y0 + rib_h;
rail_clear = 0.45;
rail_wall = 2.6;

// 3 x 5 inch card, portrait, with room to slide a laminated card in.
card_w = 76.2;
card_h = 127;
slot_w = card_w + 1.6;
slot_h = card_h + 8;
bite = 3.2;
side_wall = 6;
divider_w = 5;
join_w = 16;
bottom_rail = 6;
panel_h = bottom_rail + slot_h + 9;
groove_z0 = 1.0;
groove_z1 = 2.8;
pocket_z0 = 4.2;
panel_z = 6.6;
seat_d = 23.8;
hole_d = 10;
label_font = "Liberation Sans:style=Bold";

function half_w() = side_wall + 2 * slot_w + divider_w + join_w;
function card_panel_w() = 2 * half_w() - join_w;
function ledge_x0() = -ext_w;
function ledge_x1() = plate_w + ext_w;

module plate_place() {
  translate([0, hinge_y, foot_t])
    rotate([plate_rot, 0, 0])
      children();
}

module m3_hole(h) {
  cylinder(h = h, d = m3_clear, $fn = 32);
}

module pilot_hole(h) {
  cylinder(h = h, d = m3_pilot, $fn = 28);
}

module cable_port_cut() {
  translate([
    ring_port_x - ring_port_w / 2,
    ring_port_y - ring_port_h / 2,
    -2
  ])
    cube([ring_port_w, ring_port_h, foot_t + cap_t + 6]);
}

module stand_cap() {
  difference() {
    union() {
      cube([box_x, box_y, cap_t]);
      translate([0, box_y, 0])
        cube([16, 36, cap_t]);
      translate([box_x - 16, box_y, 0])
        cube([16, 36, cap_t]);
      translate([6, 4, cap_t - 0.4])
        linear_extrude(1.1)
          text("FRONT", size = 5, font = label_font, halign = "left");
    }
    translate([68, 46, -1])
      cube([64, 40, cap_t + 2]);
    cable_port_cut();
    for (x = stand_bolt_xs)
      translate([x, stand_bolt_y, -1])
        m3_hole(cap_t + 2);
    translate([8, 158, -1])
      m3_hole(cap_t + 2);
    translate([box_x - 8, 158, -1])
      m3_hole(cap_t + 2);
  }
}

module slope_plate(x0, x1) {
  translate([x0, -4, -plate_t])
    cube([x1 - x0, plate_h + 4, plate_t]);
}

module slope_ledge(x0, x1) {
  translate([x0, 0, 0])
    cube([x1 - x0, floor_y, channel_d]);
  translate([x0, 0, stop_z0])
    cube([x1 - x0, rib_y0, stop_z1 - stop_z0]);
  translate([x0, rib_y0, stop_z0])
    cube([x1 - x0, rib_h, stop_z1 - stop_z0]);
}

module width_ticks(x0, x1) {
  ticks = [
    [97.7, "mini"],
    [125.3, "10"],
    [140.8, "13"],
    [card_panel_w() / 2, "card"]
  ];
  for (tick = ticks) {
    for (s = [-1, 1]) {
      x = 100 + s * tick[0];
      if (x > x0 + 8 && x < x1 - 8)
        translate([x, floor_y + 4, stop_z1 - 0.2])
          linear_extrude(0.8)
            text(tick[1], size = 3.4, font = label_font, halign = "center", valign = "center");
    }
  }
}

module cable_notch_local() {
  translate([ring_port_x - ring_port_w / 2, -1, -plate_t - 1])
    cube([ring_port_w, floor_y + 6, plate_t + channel_d + 2]);
  translate([ring_port_x - ring_port_w / 2, 8, -plate_t - 0.2])
    cube([ring_port_w, 90, 2.6]);
}

module foot_solid(x0, x1) {
  translate([x0, foot_y0, 0])
    cube([x1 - x0, foot_y1 - foot_y0, foot_t]);
}

module center_plate() {
  difference() {
    union() {
      foot_solid(0, plate_w);
      plate_place() {
        slope_plate(0, plate_w);
        slope_ledge(0, plate_w);
        width_ticks(0, plate_w);
      }
    }
    translate([-0.2, foot_y0 - 0.2, foot_t - lap_t])
      cube([lap_x + 0.2, foot_y1 - foot_y0 + 0.4, lap_t + 1]);
    translate([plate_w - lap_x, foot_y0 - 0.2, foot_t - lap_t])
      cube([lap_x + 0.2, foot_y1 - foot_y0 + 0.4, lap_t + 1]);
    for (x = stand_bolt_xs)
      translate([x, stand_bolt_y, -1])
        m3_hole(foot_t + 2);
    cable_port_cut();
    translate([
      ring_port_x - ring_port_w / 2,
      ring_port_y - 1,
      foot_t - 4
    ])
      cube([ring_port_w, hinge_y - ring_port_y + 8, 5]);
    plate_place()
      cable_notch_local();
    for (y = [100, 112]) {
      translate([10, y, foot_t - lap_t - 4.2])
        pilot_hole(4.4);
      translate([plate_w - 10, y, foot_t - lap_t - 4.2])
        pilot_hole(4.4);
    }
  }
}

module extension_left() {
  difference() {
    union() {
      foot_solid(-ext_w, -part_gap);
      translate([-part_gap, foot_y0, foot_t - lap_t])
        cube([lap_x + part_gap, foot_y1 - foot_y0, lap_t]);
      plate_place() {
        slope_plate(-ext_w, -part_gap);
        slope_ledge(-ext_w, -part_gap);
        width_ticks(-ext_w, -part_gap);
      }
    }
    for (y = [100, 112])
      translate([10, y, foot_t - lap_t - 1])
        m3_hole(lap_t + 2);
  }
}

module extension_right() {
  translate([100, 0, 0])
    mirror([1, 0, 0])
      translate([-100, 0, 0])
        extension_left();
}

module rail_local() {
  solid_y0 = rib_y0 - rail_clear;
  solid_y1 = rib_y1 + rail_wall + rail_clear;
  z0 = stop_z0 - rail_wall;
  z1 = stop_z1 + rail_wall;
  difference() {
    union() {
      translate([-16, solid_y0, z0])
        cube([32, solid_y1 - solid_y0, z1 - z0]);
      translate([10, floor_y, 1.2])
        cube([rail_wall, rib_y0 - floor_y + rail_wall, channel_d - 1.2]);
    }
    translate([-20, solid_y0 - 1, stop_z0 - rail_clear])
      cube([40, rib_h + 2 * rail_clear + 1, (stop_z1 - stop_z0) + 2 * rail_clear]);
    translate([0, rib_y1 - 0.2, (stop_z0 + stop_z1) / 2])
      rotate([-90, 0, 0])
        pilot_hole(rail_wall + 2);
  }
}

module rail_print() {
  translate([32, 20, -1.54])
    rotate([-90, 0, 0])
      translate([-16, -rib_y1 - rail_wall - 2, -stop_z1 - rail_wall])
        rail_local();
}

module nut_recess(d, h) {
  cylinder(h = h, d = d / cos(30), $fn = 6);
}

function slot_x0(i, join_on_right) =
  (join_on_right ? side_wall : join_w) + i * (slot_w + divider_w);

module card_window(x, y, z, w, h, t) {
  translate([x, y, z])
    cube([w, h, t]);
}
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

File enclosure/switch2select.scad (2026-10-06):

// Switch2Select enclosure
// Copyright (C) 2026 Switch2Select contributors
// SPDX-License-Identifier: CERN-OHL-W-2.0
// Original hardware design. Inspired by Chatterbox, Copyright (c) 2025 Neil Squire.
// https://github.com/makersmakingchange/Chatterbox

// "bottom", "lid", or "both" (bottom and lid side by side).
part = "both"; // [bottom, lid, both]

// Assembled outside size. The lid skin sits on the bottom rim.
outer_x = 200;
// Opposing cradles, cord exits, and wrap stems clear at this depth, with
// room between them for the ESP32, relay module, and speech module.
outer_y = 140;
outer_z = 55;
wall = 2.4;
// Outside vertical corners. Flat faces keep the full outside size.
corner_r = 6;

floor_t = wall;
lid_t = wall;
bottom_z = outer_z - lid_t;

// Lid lip drops inside the bottom opening.
fit_gap = 0.4;
lip_t = 2;
lip_h = 4;
layout_gap = 20;

// Corner bosses in the bottom; M3 clearance holes in the lid.
m3_clear = 3.4;
m3_tap = 2.8;
boss_od = 12;
boss_inset = 8;
pilot_depth = 10;
boss_top_gap = 0.15;

// 3.5 mm jacks push in through a 9.1 mm hole. The cradle is a hair larger
// and as deep as the jack cylinder. A shoulder stops the cylinder. The
// cord leaves through that shoulder. A round cord binds in a hole of its
// own width, so the passage is 0.4 mm larger and no more.
jack_d = 9.1;
jack_cradle_clear = 0.4;
jack_body_len = 27.3;
jack_cradle_wall = 2.4;
jack_stop_t = 4;
cradle_bite = 0.2;
cord_diameter = 6.6;
cord_clear = 0.4;
// Volume buttons are 11.8 mm wide. 0.2 mm clearance (under 0.3) lets them push in.
button_w = 11.8;
button_clearance = 0.2;
button_d = button_w + button_clearance;
button_back = 9;
button_back_gap = 7.55;
button_back_t = 2.4;

// Rocker: 20 mm hole. Body behind the panel is 20.5 mm across and 25.4 mm
// deep, including the two terminals. Snap wings need a wider empty pocket.
rocker_d = 20;
rocker_body_d = 20.5;
rocker_depth = 25.4;
rocker_clear_d = rocker_body_d + 7.5;

usb_w = 12;
usb_h = 8;
sd_w = 16;
sd_h = 3;

option_count = 4;
jack_margin = 40;
input_z = 28;
scan_z = 16;
toy_z = 40;
control_z = 16;

// Partner wall, left to right when facing that wall:
// minus, plus, device, rocker, USB, microSD.
minus_x = 170;
plus_x = 140;
device_x = 122;
rocker_x = 100;
usb_x = 64;
sd_x = 32;

// Stand bolts through the lid. enclosure/stand.scad uses these same centers.
stand_bolt_y = 94;
stand_bolt_xs = [28, 64, 136, 172];

// Card-ring harness enters through the lid. stand.scad repeats this opening.
ring_port_x = 114;
ring_port_y = 96;
ring_port_w = 12;
ring_port_h = 10;

// Cord stem, inboard of each jack, fused to the floor.
stem_d = 5;
stem_head_d = 7.4;
stem_flare_h = 1.6;
stem_dx = 14;
stem_side_gap = 1.5;
stem_above = 2;

raise_h = 0.8;
raise_sink = 0.2;
numeral_size = 6;
numeral_dx = 12;
mark_gap = 2.2;
mark_stroke = 1.6;
label_font = "Liberation Sans:style=Bold";

// Grade 1 braille. Dot shape, diameter, and spacing match braille-label.
// Dot height is the proud height (ADA signage maximum).
braille_dot_d = 1.6;
braille_dot_h = 0.9;
braille_dot_spacing = 2.5;
braille_cell_spacing = 6.5;
braille_gap = 2;
braille_embed = 0.04;
braille_fn = 32;

grill_x = 42;
grill_y = 32;
grill_slot_w = 3;
grill_slot_n = 7;

button_mark_z = control_z + button_d / 2 + mark_gap + numeral_size / 2;
grill_slot_rib = (grill_y - grill_slot_n * grill_slot_w) / (grill_slot_n - 1);
lip_notch = boss_inset + boss_od / 2 + 1.5 - wall - fit_gap;
raise_total = raise_h + raise_sink;

jack_id = jack_d + jack_cradle_clear;
jack_outer_w = jack_id + 2 * jack_cradle_wall;
cord_hole_d = cord_diameter + cord_clear;
// Inward face of the student shoulder. The bite overlaps the wall only,
// so the pocket from the inner face is the full jack body.
student_cradle_end = wall + jack_body_len + jack_stop_t;
partner_cradle_end = outer_y - student_cradle_end;
cradle_end_gap = partner_cradle_end - student_cradle_end;
braille_dot_r = braille_dot_d / 2;
braille_cell_h = 2 * braille_dot_spacing + braille_dot_d;

function option_x(i) =
  jack_margin + i * (outer_x - 2 * jack_margin) / (option_count - 1);

function corner_x(i) = (i == 1 || i == 3) ? outer_x - boss_inset : boss_inset;
function corner_y(i) = (i >= 2) ? outer_y - boss_inset : boss_inset;

function dot_offset(d) = [
  d > 3 ? braille_dot_spacing : 0,
  -((d - 1) % 3) * braille_dot_spacing
];

function word_w(n) = (n - 1) * braille_cell_spacing + braille_dot_spacing + braille_dot_d;

// Partner braille reads toward -X. This is the dot-1 center of the first cell
// when the word is centered on center_x.
function partner_word_x(center_x, n) =
  center_x + (word_w(n) - braille_dot_d) / 2;

// Stem axis is past the cord exit and stem_dx off the jack axis, so the
// lead can wrap after it leaves the cylinder without closing the passage.
function student_stem_y() =
  wall + jack_body_len + jack_stop_t + stem_side_gap + stem_d / 2;

function partner_stem_y() = min(
  outer_y - wall - jack_body_len - jack_stop_t - stem_side_gap - stem_d / 2,
  outer_y - rocker_depth - stem_side_gap - stem_d / 2
);

module rounded_prism(size, r) {
  hull() {
    for (x = [r, size[0] - r])
      for (y = [r, size[1] - r])
        translate([x, y, 0])
          cylinder(h = size[2], r = r, $fn = 64);
  }
}

module hole_y(x, z, d, y0, depth) {
  translate([x, y0, z])
    rotate([-90, 0, 0])
      cylinder(h = depth, d = d, $fn = 64);
}

module slot_y(x, z, w, h, y0, depth) {
  translate([x - w / 2, y0, z - h / 2])
    cube([w, depth, h]);
}

module student_cutouts() {
  for (i = [0:option_count - 1])
    hole_y(option_x(i), input_z, jack_d, -1, wall + 2);
  hole_y(outer_x / 2, scan_z, jack_d, -1, wall + 2);
}

module partner_cutouts() {
  y0 = outer_y - wall - 1;
  depth = wall + 2;
  for (i = [0:option_count - 1])
    hole_y(option_x(i), toy_z, jack_d, y0, depth);
  hole_y(minus_x, control_z, button_d, y0, depth);
  hole_y(plus_x, control_z, button_d, y0, depth);
  hole_y(device_x, control_z, button_d, y0, depth);
  hole_y(rocker_x, control_z, rocker_d, y0, depth);
  slot_y(usb_x, control_z, usb_w, usb_h, y0, depth);
  slot_y(sd_x, control_z, sd_w, sd_h, y0, depth);
}

// U cradle opening upward. The back is a shoulder around the cord passage.
// inward is +1 on the student wall and -1 on the partner wall.
module jack_cradle(x, z, y_inner, inward) {
  id = jack_id;
  t = jack_cradle_wall;
  len = jack_body_len;
  y0 = y_inner - inward * cradle_bite;
  y_far = y_inner + inward * len;
  y_a = min(y0, y_far);
  y_b = max(y0, y_far);
  y_stop = y_far + inward * jack_stop_t;
  ys_a = min(y_far, y_stop);
  ys_b = max(y_far, y_stop);
  translate([x - id / 2 - t, y_a, z - id / 2 - t])
    cube([jack_outer_w, y_b - y_a, t]);
  translate([x - id / 2 - t, y_a, z - id / 2])
    cube([t, y_b - y_a, id]);
  translate([x + id / 2, y_a, z - id / 2])
    cube([t, y_b - y_a, id]);
  difference() {
    translate([x - id / 2 - t, ys_a, z - id / 2 - t])
      cube([jack_outer_w, ys_b - ys_a, id + t]);
    translate([x, ys_a - 0.4, z])
      rotate([-90, 0, 0])
        cylinder(h = ys_b - ys_a + 0.8, d = cord_hole_d, $fn = 48);
  }
}
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

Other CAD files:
enclosure/stand-extension-right.stl

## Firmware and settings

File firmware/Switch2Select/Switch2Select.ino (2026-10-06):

/*
 * Copyright (C) 2026 Switch2Select contributors
 * SPDX-License-Identifier: GPL-3.0-or-later
 *
 * Inspired by Chatterbox, Copyright (c) 2025 Neil Squire.
 * This file is original, not copied from that firmware.
 */

#include "device.h"
#include "web.h"

void setup() {
  deviceBegin();
  webBegin();
}

void loop() {
  deviceLoop();
  webLoop();
}

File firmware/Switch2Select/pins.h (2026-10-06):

/*
 * Copyright (C) 2026 Switch2Select contributors
 * SPDX-License-Identifier: GPL-3.0-or-later
 * This program is free software under GPL-3.0-or-later.
 * Inspired by Chatterbox, Copyright (c) 2025 Neil Squire, but this file is not derived from that firmware.
 * The DFRobot Speech Synthesis V2 library, if used, is MIT licensed. Copyright (c) DFRobot Co.Ltd.
 */

#ifndef SWITCH2SELECT_PINS_H
#define SWITCH2SELECT_PINS_H

#include <stdint.h>

// GPIO 0, 2, and 12 are strapping pins and are intentionally unused.

// VSPI defaults. Chip select is GPIO 5.
constexpr uint8_t PIN_SD_CS = 5;
constexpr uint8_t PIN_SPI_MOSI = 23;
constexpr uint8_t PIN_SPI_MISO = 19;
constexpr uint8_t PIN_SPI_SCK = 18;

// Active-low option buttons. Input-only pins; external 10k pull-ups, no internal pull-up.
constexpr uint8_t PIN_OPTION_0 = 34;
constexpr uint8_t PIN_OPTION_1 = 35;
constexpr uint8_t PIN_OPTION_2 = 36;
constexpr uint8_t PIN_OPTION_3 = 39;

// Active-low, internal pull-up.
constexpr uint8_t PIN_SCAN = 32;
constexpr uint8_t PIN_VOLUME_UP = 27;
constexpr uint8_t PIN_VOLUME_DOWN = 33;
constexpr uint8_t PIN_DEVICE = 14;

// Data for four 7-LED WS2812B rings behind the flash cards.
// GPIO 25 and 26 are unused. The student wall has no LED holes.
constexpr uint8_t PIN_RING_DATA = 13;

// Active-low relay modules. HIGH keeps the coil off.
constexpr uint8_t PIN_RELAY_0 = 4;
constexpr uint8_t PIN_RELAY_1 = 15;
constexpr uint8_t PIN_RELAY_2 = 21;
constexpr uint8_t PIN_RELAY_3 = 22;

// UART2 to the DFRobot Gravity Speech Synthesis V2 module.
// RX receives module D/T. TX drives module C/T.
constexpr uint8_t PIN_SPEECH_RX = 16;
constexpr uint8_t PIN_SPEECH_TX = 17;

#endif

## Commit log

2026-10-06 Add Switch2Select with a lid rail for an iPad or four cards.
    Speech names the active port, rings behind the cards replace lamps aimed at the student, and a partner button repeats that port and talks to the page.
    [stand-cap.stl, stand-cards-left.stl, stand-cards-right.stl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]
2026-10-06 Note that the sample Look video is included on the card.
2026-10-06 Update README.md to clarify stand design and assembly instructions; modify SCAD file for card placement adjustment. The full stand now supports an iPad in landscape and includes detailed screw specif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
    [stand-simple-stop.stl, stand-simple.scad, stand-simple.stl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]
2026-10-06 Brace the simple stand back into the shelf so the joint is harder to snap.
    [stand-simple.scad, stand-simple.stl]
2026-10-06 Round the enclosure and simple stand corners so the prints are softer to handle.
    [stand-simple-stop.stl, stand-simple.scad, stand-simple.stl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]
2026-10-08 Keep each choice on screen, and add switch games that stay in motion.
    Pictures, words, and videos now hold auto scan long enough to look or finish. Look, Chase, Pop, and Drum take the four switches or the scan switch, and the choices return when the game has been quiet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
